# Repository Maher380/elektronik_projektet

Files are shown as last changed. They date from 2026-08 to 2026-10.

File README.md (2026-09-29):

# 🔥 CnB - Crash and Burn

Autonomous car school project built with C++ and ESP-IDF for the ESP32-S3.

This repository is used by team **CnB (Crash and Burn)** to develop the
software for an autonomous competition car.

The project starts from an ESP32-S3 driver library and includes:

- hardware abstraction through driver interfaces
- ESP32-S3 implementations for hardware-level code
- stubs for testing without hardware
- factory-based driver creation
- ESP-IDF CMake project structure

## Project Layout

```text
.
+-- 📁 firmware/                  ESP-IDF firmware project for the ESP32-S3
|   +-- CMakeLists.txt             Firmware project entry point
|   +-- 📁 main/                   Main ESP-IDF component
|       +-- CMakeLists.txt         Component source list and dependencies
|       +-- Kconfig.projbuild      Project configuration used by menuconfig
|       +-- 📁 include/            Public C++ headers
|       |   +-- 📁 driver/         Hardware driver interfaces and implementations
|       |   +-- 📁 system/         System-level interfaces and logic headers
|       +-- 📁 source/             C++ source files
|           +-- 📁 driver/         ADC, GPIO, timer, WiFi and serial drivers
|           +-- 📁 system/         Application logic and pin manager
|           +-- main.cpp           ESP-IDF application entry point
+-- 📁 hardware/                  Hardware design files
|   +-- 📁 kicad/                  KiCad schematics, PCB layout and exports
|   +-- 📁 ltspice/                LTspice simulations and component models
+-- README.md                      Project overview and workflow rules
+-- THIRD_PARTY_NOTICES.md         Attribution for imported starter code
```

The repository is split into two main areas:

- 📁 `firmware/` contains all software and embedded code.
- 📁 `hardware/` contains electronics design files, simulations and exports.

## Build

Use the ESP-IDF shell to build and flash:

```bash
cd firmware
idf.py set-target esp32s3
idf.py build
idf.py -p <PORT> flash monitor
```

Serial output is enabled over USB for later sensor testing. The application
prints `CnB serial ready` after the serial driver starts.

WiFi settings are configured with:

```bash
idf.py menuconfig
```

Open `Autonomous car network configuration` and set SSID and password. Do not
commit generated `sdkconfig` files with private credentials.

## Hardware

Hardware files are stored in `hardware/`.

- 📁 `hardware/kicad/` - KiCad project files for schematics, PCB layout, symbols, footprints and generated exports.
- 📁 `hardware/ltspice/` - LTspice simulation files, component models and circuit experiments.

## Branch Naming

Do not work directly on `main`. Create a branch for every task.

Branch names must use this format:

```text
<type>/<short-english-title>
```

Use a short English title. Prefer lowercase words separated with hyphens.

Allowed branch types:

- `feature/` - new functionality
- `fix/` - fixes for broken behavior
- `docs/` - documentation-only work
- `experiment/` - exploratory work not meant to be permanent
- `refactor/` - internal code cleanup without changing behavior
- `test/` - test-only changes
- `chore/` - maintenance, tooling or dependency updates
- `release/` - preparing a release
- `ci/` - pipeline or automation changes

Examples:

```bash
git switch -c docs/create-diary-structure
git switch -c feature/support-ir-sensor
```

If a branch belongs to a Jira task, include the Jira key in commits and pull
request titles:

```bash
git commit -m "CAR-12 support IR sensor"
```

## Pull Requests

Push your branch and open a pull request into `main`.

Each pull request should include:

- what was changed
- how it was tested
- the related Jira task, if one exists

## Vagrant system logic

The Vagrant logic runs the integrated IR/motor/servo loop. `main.cpp` starts
the target logic selected under Target car in `idf.py menuconfig`. Ford and the
third car are placeholders that leave the motor disabled until implemented.
See [system test setup and MQTT extensions](documentation/guides/main_system_test.md)
for wiring, behavior, configuration and host tests.

## Attribution

This project includes code derived from
`OliverEdman/cpp-driver-library-p02`, licensed under MIT. See
`THIRD_PARTY_NOTICES.md`.

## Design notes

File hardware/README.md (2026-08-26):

# Hardware

Hardware design files for the CnB autonomous car.

- `kicad/` contains KiCad project files for schematics and PCB layout.
- `ltspice/` contains LTspice simulations and component models.

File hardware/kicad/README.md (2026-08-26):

# KiCad

Place KiCad files here.

Typical files:

- `*.kicad_pro` - KiCad project
- `*.kicad_sch` - schematic
- `*.kicad_pcb` - PCB layout
- `symbols/` - project symbols
- `footprints/` - project footprints
- `exports/` - generated PDFs, Gerbers and BOM files

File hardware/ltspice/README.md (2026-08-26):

# LTspice

Place LTspice files here.

Typical files:

- `*.asc` - schematic simulation
- `*.asy` - custom symbols
- `*.lib` - component models
- `models/` - external models
- `simulations/` - simulation circuits

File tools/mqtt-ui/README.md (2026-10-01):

# MQTT-webbpanelen

Webbpanelen visar tio sekunders historik för tre IR-sensorer, begärd styrvinkel och motorpådrag. Här kan du starta/stoppa bilen och ändra körläge, duty, stoppavstånd och telemetriintervall.

**Ford:** kör `.\tools\mqtt-ui\start-ui.ps1 -Car ford`, se [Ford-guiden](../../documentation/guides/ford_manual_by_remote.md).

**Första gången:** följ [guiden från installation till körning](../../documentation/guides/mqtt_steg_for_steg.md).
För den integrerade körloopen, se även [systemtest och provade inställningar](../../documentation/guides/main_system_test.md).

**Redan konfigurerat:** starta brokern och bilen enligt steg 5 i guiden. Kör sedan från projektroten:

```powershell
cd 'C:\projekt\elektronik_projektet'
.\tools\mqtt-ui\start-ui.ps1
```

Byt sökvägen mot din egen projektrot. Öppna **http://127.0.0.1:8765** och kontrollera **LIVE MQTT**, **BROKER CONNECTED** och **CAR RECEIVING**.

**Andra enheter (t.ex. en telefon på cnb-net):** klicka på **LAN OFF** överst på sidan
på http://127.0.0.1:8765. Den visar då adressen att öppna på telefonen. Knappen syns och
fungerar bara på 127.0.0.1, och LAN-åtkomsten är alltid avstängd när servern startar.
Tillåt Node.js i Windows-brandväggen första gången. Alla på nätet kan då styra bilen.

Ändra inställningar med **Apply settings** och invänta kvittens. **Start car** aktiverar körning; **Stop car** avarmerar. Kör inte `run-car.ps1` samtidigt som panelen styr bilen.

Med systemtest-firmware visas även **Reaction distance**, **Loop interval** och
**Stop motor & test servo**. Servotestet stoppar motorn och ställer önskad vinkel;
ett nytt Start återgår till navigationen. Sensorernas beslutsavstånd visas separat
från mätvärdena. Systemtestet använder endast körläget `decide_action`.

För att prova panelen utan bil eller broker:

```powershell
.\tools\mqtt-ui\start-ui.ps1 -Demo
```

Demo använder simulerade värden och en förenklad körmodell, inte bilens exakta
väggkorrigering. Avsluta servern med **Ctrl+C** innan du byter läge.

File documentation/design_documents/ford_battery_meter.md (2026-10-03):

# Ford: Battery Meter

The Ford measures its drive battery (2S LiPo, 6.0–8.4 V) through a resistor
divider on `A3` (GPIO4). The firmware sends the voltage as `battery_v` in
`cnb/ford/telemetry`, and the Ford web page shows it on the BATTERY tile.

## Circuit

| Part | Nominal | Measured | From | To |
| --- | --- | --- | --- | --- |
| R1 | 100 kΩ | 101.24 kΩ | Battery + (after the switch) | `A3` |
| R2 | 33 kΩ | 32.99 kΩ | `A3` | `GND` |
| C1 | 150 nF (marked `154`) | 154 nF | `A3` | `GND` |

Battery voltage = pin voltage × (R1 + R2) / R2 ≈ pin voltage × 4.069, using
the measured values. C1 does not change the conversion; it gives the ADC a
steady charge to sample from. It is not a parameter in the code.

The meter averages its last 16 reads, one every 100 ms, so `battery_v` is
the average over about 1.6 s.

## Calibration points

Each row compares a multimeter on the battery terminals with `battery_v` at
the same moment. Add a row whenever you have a multimeter at hand,
preferably at other voltages, so the points spread over 6.0–8.4 V.

| Date | Multimeter (V) | `battery_v` (V) | Error (V) | Conditions |
| --- | --- | --- | --- | --- |
| 2026-10-03 | 7.38 | 7.34 | −0.04 (−0.5 %) | Not recorded. Firmware without correction. |

Write down the conditions (car standing still or driving, motors on or off),
because the voltage sags under load and the 1.6 s average lags behind it.

## Using the points

No correction is applied yet: −0.5 % is about 10 mV at the pin, which is
within the ESP32-S3 ADC's accuracy after its own calibration.

- **One point:** a gain factor, multimeter / `battery_v` (now 7.38 / 7.34 ≈ 1.005).
- **Two or more points, spread over the range:** a straight-line fit,
  multimeter = a × `battery_v` + b, which corrects both gain and offset.

The correction belongs where the battery is read in `fordLogic.cpp`, not in
`voltage_meter::Divider`, which stays a plain divider for any circuit.

A battery level (percent or time left) needs more than this: the LiPo's
discharge curve from voltage to charge. Calibrated voltages are the first
step towards it.

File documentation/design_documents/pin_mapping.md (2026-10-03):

# Arduino Nano ESP32: Code-To-Pin Reference

The driver factory uses the **ESP32-S3 GPIO number**, not the Arduino pin
number printed on the board.

> `factory.gpioOutput(2)` selects **GPIO2 = A1**, not Arduino pin D2.
> To select the board pin **D2**, use `factory.gpioOutput(5)` or
> `factory.pwm(5)`.

The `~` symbol marks a PWM-capable Arduino pin. The symbol is only a visual
label; it is not written in the C++ call.

## Pins Used By CnB - Vagrant

These are the calls and physical pins used by the current three-sensor code on
`SCRUM-56-fix-adc-support-for-multiple-ir-sensors`.

| Driver call | Pin on Arduino | Driver function | Connected hardware | Status |
| --- | --- | --- | --- | --- |
| `factory.adc(1)` | `A0 / ~D17` | 📈 ADC1_CH0 | Left IR sensor output | 🔵 Used |
| `factory.adc(2)` | `A1 / ~D18` | 📈 ADC1_CH1 | Center IR sensor output | 🔵 Used |
| `factory.adc(4)` | `A3 / ~D20` | 📈 ADC1_CH3 | Right IR sensor output | 🔵 Used |
| `factory.pwm(5)` | `~D2` | 〰️ PWM output | MP6550 IN1, forward | 🔵 Used |
| `factory.pwm(6)` | `~D3` | 〰️ PWM output | MP6550 IN2, reverse | 🔵 Used |
| `factory.gpioOutput(7)` | `~D4` | 🔌 Digital output | MP6550 nSLEEP | 🔵 Used |
| `factory.pwm(9)` | `~D6` | 〰️ PWM output | steering servo | 🔵 Used |
| `factory.odometer(18)` | `~D9` | 🔌 Digital input (interrupt) | A3144 Hall-effect odometer sensor | 🔵 Used |
| `factory.gpioInput(10)` | `~D7` | 🔌 Digital input (interrupt) | SRF05 Echo, via 5 V → 3.3 V divider | 🔵 Used |
| `factory.gpioOutput(17)` | `~D8` | 🔌 Digital output | SRF05 Trigger | 🔵 Used |

Power connections do not use driver factory calls:

| Pin on Arduino | Connection |
| --- | --- |
| `VIN` | Approximately 7.2 V battery supply after the power switch |
| `GND` | Common ground for Arduino, MP6550, regulator, and sensors |
| External regulated 5 V rail | IR sensor and/or SRF05 power; the demo used an L7805CV |

## Pins Used By CnB - Ford

| Driver call | Pin on Arduino | Driver function | Connected hardware | Status |
| --- | --- | --- | --- | --- |
| `factory.gpioOutput(5)` | `~D2` | ⚡ Digital output | A89301 BRAKE (high = brake) | 🔵 Used |
| `factory.gpioOutput(7)` | `~D4` | ⚡ Digital output | A89301 DIR | 🔵 Used |
| `factory.pwm(8)` | `~D5` | 〰️ PWM output, 20 kHz | A89301 SPD/SCL (speed) | 🔵 Used |
| `factory.pwm(9)` | `~D6` | 〰️ PWM output | steering servo (pulse width) | 🔵 Used |
| `factory.adc(4)` | `A3 / ~D20` | 📈 ADC1_CH3 | Drive battery voltage divider: R1 101.24 kΩ from battery + (after the switch), R2 32.99 kΩ and 154 nF to `GND` | 🔵 Used |

## Code Value To Board Pin

Use the first column when passing a pin to `gpioInput()`, `gpioOutput()`,
`pwm()`, or `adc()`.

### Legend

| Symbol | Meaning |
| --- | --- |
| 🔵 | Used by the current CnB firmware |
| 🟢 | Available for a future connection |
| 🟡 | Available, but shared with a standard peripheral or onboard function |
| 🔴 | Avoid; blocked by the current pin manager |
| ✅ | Supported by the current driver |
| ⚠️ | Supported by the chip, but not by the current ADC1-only driver |
| `~` | PWM-capable Arduino pin |

| GPIO in code | Pin on Arduino | ADC status | PWM status | Common function | Availability |
| ---: | --- | --- | --- | --- | --- |
| `0` | `B1 / ~D15` | - | 🔴 Blocked | RGB LED green / strapping | 🔴 Avoid |
| `1` | `A0 / ~D17` | ✅ ADC1_CH0 | ✅ | Analog / digital | 🔵 Left IR sensor |
| `2` | `A1 / ~D18` | ✅ ADC1_CH1 | ✅ | Analog / digital | 🔵 Center IR sensor |
| `3` | `A2 / ~D19` | 🔴 ADC1_CH2 blocked | 🔴 Blocked | Strapping | 🔴 Avoid |
| `4` | `A3 / ~D20` | ✅ ADC1_CH3 | ✅ | Analog / digital | 🔵 Right IR sensor |
| `5` | `~D2` | ✅ ADC1_CH4 | ✅ | Digital / PWM | 🔵 MP6550 IN1 |
| `6` | `~D3` | ✅ ADC1_CH5 | ✅ | Digital / PWM | 🔵 MP6550 IN2 |
| `7` | `~D4` | ✅ ADC1_CH6 | ✅ | Digital / PWM | 🔵 MP6550 nSLEEP |
| `8` | `~D5` | ✅ ADC1_CH7 | ✅ | Digital / PWM | 🟢 Available |
| `9` | `~D6` | ✅ ADC1_CH8 | ✅ | Digital / PWM | 🔵 Steering servo |
| `10` | `~D7` | ✅ ADC1_CH9 | ✅ | Digital / PWM | 🔵 SRF05 Echo |
| `11` | `A4 / ~D21` | ⚠️ ADC2_CH0 | ✅ | I2C SDA | 🟡 Shared function |
| `12` | `A5 / ~D22` | ⚠️ ADC2_CH1 | ✅ | I2C SCL | 🟡 Shared function |
| `13` | `A6 / ~D23` | ⚠️ ADC2_CH2 | ✅ | Analog / digital | 🟢 Available |
| `14` | `A7 / ~D24` | ⚠️ ADC2_CH3 | ✅ | Analog / digital | 🟢 Available |
| `17` | `~D8` | ⚠️ ADC2_CH6 | ✅ | Digital / PWM | 🔵 SRF05 Trigger |
| `18` | `~D9` | ⚠️ ADC2_CH7 | ✅ | Digital / PWM | 🔵 Odometer (A3144 Hall sensor) |
| `21` | `~D10` | - | ✅ | Digital / PWM | 🟢 Available |
| `38` | `~D11` | - | ✅ | SPI COPI | 🟡 Shared function |
| `43` | `~D1 / TX0` | - | ✅ | UART transmit | 🟡 Shared function |
| `44` | `~D0 / RX0` | - | ✅ | UART receive | 🟡 Shared function |
| `45` | `~D16` | - | 🔴 Blocked | RGB LED blue / strapping | 🔴 Avoid |
| `46` | `B0 / ~D14` | - | 🔴 Blocked | RGB LED red / strapping | 🔴 Avoid |
| `47` | `~D12` | - | ✅ | SPI CIPO | 🟡 Shared function |
| `48` | `~D13` | - | ✅ | SPI SCK / built-in LED | 🟡 Shared function |

GPIO values not listed above are not exposed as normal Arduino Nano ESP32
header pins. Do not use them only because `PinManager::isPinValid()` returns
true; the current pin manager does not verify that a GPIO is physically exposed
on this board.

## How The Factory Interprets A Number

| Code | Meaning |
| --- | --- |
| `factory.gpioInput(n)` | Configure GPIO `n` as a digital input |
| `factory.gpioOutput(n)` | Configure GPIO `n` as a digital output |
| `factory.pwm(n)` | Route a PWM output to GPIO `n` |
| `factory.adc(n)` | Use GPIO `n` as an ADC1 input if it maps to ADC1 |

For example:

```cpp
auto leftSensor = factory.adc(1);        // GPIO1 -> A0 -> ADC1_CH0
auto motorIn1 = factory.pwm(5);          // GPIO5 -> ~D2
auto motorSleep = factory.gpioOutput(7); // GPIO7 -> ~D4
```

The three IR sensors share one `ADC_UNIT_1` handle and use channels 0, 1, and
3. The ADC2-capable pins shown in the table cannot be initialized by the
current ADC driver because it deliberately accepts ADC1 only.

## Power And Control Pins

| Pin on Arduino | Type | Meaning |
| --- | --- | --- |
| `VIN` | Power input | External supply input for the Nano ESP32 |
| `3V3` | Power output | Regulated 3.3 V output; GPIO is not 5 V tolerant |
| `VUSB` | Power output | USB-derived supply; do not assume it is active from VIN |
| `GND` | Ground | Common electrical reference |
| `RESET` | Control input | Reset when pulled low |

## Sources

- [Arduino Nano ESP32 full pinout](https://docs.arduino.cc/resources/pinouts/ABX00083-full-pinout.pdf)
- [Arduino Nano ESP32 datasheet](https://docs.arduino.cc/resources/datasheets/ABX00083-datasheet.pdf)
- [Espressif ESP32-S3 GPIO reference](https://docs.espressif.com/projects/esp-idf/en/stable/esp32s3/api-reference/peripherals/gpio.html)

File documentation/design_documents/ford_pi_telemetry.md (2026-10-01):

# Ford: Raspberry Pi telemetry over MQTT

The contract between the Ford's Raspberry Pi (code in the `slam_test` repo) and the
web page in this repo (`tools/mqtt-ui`). The Pi reports what it **measures** with the
camera through SLAM, so the operator can compare it with what the car was **asked**
to do. Terms are defined in [CONTEXT.md](../../CONTEXT.md): *measured speed*,
*wheel angle*, *steering command*, *speed command*.

## Topics

| Topic | Retained | QoS | Sent |
| --- | --- | --- | --- |
| `cnb/ford/pi/telemetry` | no | 0 | every 200 ms |
| `cnb/ford/pi/status` | yes | 1 | on connect, and as the MQTT last will |

The Pi is part of the Ford, so its topics sit under `cnb/ford`. It has its own
status, so the page can tell "Pi offline" from "ESP offline".

## Broker login

- Username and password: the same as the Ford's ESP, `cnb-ford`.
- **Client ID: `cnb-ford-pi`.** It must differ from the ESP's (`cnb-ford`); two
  clients with the same ID keep disconnecting each other.
- The ACL ([mosquitto-acl.example](../../tools/mqtt/mosquitto-acl.example)) lets
  `cnb-ford` write both Pi topics and `cnb-dashboard` read them.
- The broker is on the car network, `mqtt://192.168.137.1:1883`.

## `cnb/ford/pi/status`

Exactly like the ESP's status:

```json
{ "schema_version": 1, "online": true }
```

Publish it retained when connected, and register
`{ "schema_version": 1, "online": false }` (retained) as the last will so the broker
reports the Pi offline if it drops off.

## `cnb/ford/pi/telemetry`

```json
{
  "schema_version": 1,
  "measured_speed_mps": { "slam": 0.42 },
  "wheel_angle_deg": { "slam": -12.3 },
  "slam_state": "tracking",
  "cpu_temp_c": 61.2
}
```

| Field | Unit | Meaning |
| --- | --- | --- |
| `schema_version` | — | Always `1`. Other versions are ignored. |
| `measured_speed_mps` | m/s | Measured speed, one entry per source. Positive is forward. |
| `wheel_angle_deg` | degrees | Wheel angle, one entry per source. Negative is left, 0 straight ahead, positive right. |
| `slam_state` | — | `"tracking"`, `"lost"` or `"starting"`. Anything else makes the page ignore the message. |
| `cpu_temp_c` | °C | The Pi's CPU temperature. |

### Sources

A real-world value is always reported with its source. The key names the source,
the value is a number or `null`:

- `slam`: worked out by SLAM from the camera. The only source so far.
- Later sources get their own key, for example
  `"measured_speed_mps": { "slam": 0.42, "odometer_left_rear": 0.45 }`.
  Keys use `a-z`, `0-9` and `_`, at most 32 characters.

### When a value is `null`

- `slam_state` is not `"tracking"`: both SLAM values are `null`.
- The car moves slower than **0.2 m/s**: the SLAM wheel angle is `null`. It is worked
  out from turn rate and speed, so it is unknown when the car stands still or creeps.
  Tune the threshold in `slam_test`.
- Any value the Pi cannot work out: `null`, never a made-up 0.

## What the page does with it

- **Status strip, PI · SLAM:** SLAM state, or STALE/OFFLINE; CPU temperature amber
  from 70 °C, red from 80 °C ("throttling, SLAM may lag"; the Pi 5 slows itself down
  at about 80–85 °C).
- **Steering card:** the SLAM wheel angle beside the steering command converted to
  degrees with the Ford's full-lock angle (`FULL_LOCK_DEG` in `public/ford.mjs`,
  a placeholder of 25° until measured). A difference above 5° is flagged.
- **Speed card:** the SLAM measured speed beside the speed command, not converted:
  without a speed loop a speed command has no fixed m/s.
- **Charts:** the last 30 seconds of command and measured, for steering and speed.
- **Freshness:** the page assumes the fixed 200 ms rate and treats Pi data older than
  500 ms as stale. If the Pi's rate changes, change `PI_INTERVAL_MS` in `core.mjs`
  and `public/ford.mjs` too.
- **Demo:** `start-ui.ps1 -Car ford -Demo` simulates the Pi with this payload.

## Checking from the laptop

```powershell
& 'C:\Program Files\mosquitto\mosquitto_sub.exe' -h 127.0.0.1 -u cnb-dashboard -P <password> -t 'cnb/ford/pi/#' -v
```

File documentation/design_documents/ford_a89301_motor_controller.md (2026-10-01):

# Ford: A89301 BLDC Motor Controller

## Human introduction
Initially the A89301 had bad settings for the ford Engine. In order to fix this a configuration application which communicated with the A89301 from the esp32s3 through I2C was developed. This tool can also be used to tune the A89301 later on.

## AI text

Bench bring-up and tuning of the drive motor for **ford**, done on branch
`feature/add_A89301_motor_driver` (September 2026). The car was on a stand,
wheels in the air, powered from a lab supply at 7.4 V. All numbers below are
**without load** unless stated otherwise.

## Hardware

| Part | Details |
| --- | --- |
| Motor controller | Pololu A89301-based sensorless brushless motor controller, 50 V, 11 A (Pololu 5357, board `md47a`) |
| Motor | Sensorless brushless, 8000 KV, 3 wires, about 0.5 Ω phase to phase (measured) |
| Pole pairs | 1 (derived: 12 Hz electrical per wheel rev/s matches 8000 KV at 1 pole pair and a gear ratio of about 12) |
| Wheel | 34 mm diameter, 0.107 m circumference |
| Controller MCU | Arduino Nano ESP32 (ESP32-S3) |

The A89301 is a field-oriented (FOC) sensorless controller. It estimates the
rotor position from the motor model (resistance, inductance) and an observer
with gains `PID_P` and `PID_I`. These parameters must fit the motor.

## Wiring

### Configuration wiring (I2C), used by `A89301_CONFIG_MODE`

| A89301 board | ESP32-S3 (Nano pin / GPIO) | Notes |
| --- | --- | --- |
| VIN, GND (screw terminal) | – | 7.4 V supply (2S LiPo range 6.4–8.4 V) |
| SA, SB, SC | – | Motor phases |
| GND (header) | GND | Common ground is required |
| IOREF | 3V3 | Logic level 3.3 V. Also powers the FAULT LED |
| SPD/SCL | A5 / GPIO12 | I2C SCL. **Add 4.7 kΩ pull-up to 3.3 V** (the board has none on SCL) |
| FG/SDA | A4 / GPIO11 | I2C SDA. The board has a pull-up to IOREF |
| DIR | D4 / GPIO7 | High = forward in the test apps |
| BRAKE | D2 / GPIO5 | High = brake. **Fit a 10–12 kΩ pull-up to 2V8**, see Safety |
| FLT | not connected | Open drain, pulled up to IOREF |
| – | D9 / GPIO18 | A3144 wheel odometer, 1 magnet per revolution |
| – | A0 / GPIO1 | TMP36 on the motor can (ADC1) |

### PWM wiring, used by `MOTOR_TEST_MODE`

Same as above, but SPD is driven with 20 kHz PWM from **D5 / GPIO8** instead of
the I2C bus: **move the SPD/SCL wire from A5 to D5**. The A89301 EEPROM is
configured for PWM speed input (`SPD_MODE` 0, `CLOCK_PWM` 0, `PWMIN_RANGE` 0 =
PWM above 2.8 kHz).

The motor test app does not use FG/SDA (A4), FLT, the odometer (D9) or the
TMP36 (A0). They may stay connected.

Speed is set as a PWM duty 0.0–1.0 over the serial monitor. Start with at least
0.08, lower to 0.065 for the slowest steady speed and stay at or below 0.7 (see
Measured performance).

> **The motor test app has no motor temperature, stall or speed limit
> protection.** Keep runs short and watch the motor. Use the configuration app
> for longer tests.

## Saved A89301 configuration

Only three EEPROM words were changed from the configuration we received. All
Allegro-only bits are at their default values (checked by the programmer before
writing).

| EEPROM address | Original | Saved | Changed fields |
| --- | --- | --- | --- |
| 12 | `0x0028` | `0x01FF` | `PID_P` 40 → **255**, `MOTOR_INDUCTANCE` 0 → **1** |
| 13 | `0x011E` | `0x0114` | `PID_I` 30 → **20** |
| 21 | `0xC020` | `0xC120` | `SPEED_INPUT_OFF_THRESHOLD` 10 % → **6 %** |

To restore the original configuration, write the original values back to
addresses 12, 13 and 21.

Full EEPROM contents after saving (addresses 8–22):

```
 8 0x275E    12 0x01FF    16 0x0A6C    20 0x0B25
 9 0x7120    13 0x0114    17 0x2000    21 0xC120
10 0x00DC    14 0x0E15    18 0x8E0D    22 0x925E
11 0xD880    15 0x39B1    19 0x5500
```

Other relevant settings (unchanged): open loop speed control
(`SPEED_CLOSE_LOOP` 0), `RATED_SPEED` 1886 (1000 Hz), `RATED_VOLTAGE` 7.4 V,
`RATED_CURRENT` 2.5 A (current limit about 3.25 A), `MOTOR_RESISTANCE` 113
(about 0.24 Ω phase to centre, matches the measurement), `FG_PIN_DIS` 1 (FG
always high, I2C friendly), `RESTART_ATTEMPT` 3 times, standby disabled.

## Tuning conclusions

**Symptom:** the motor accelerated for about 2 s and then stopped without a
fault. The chip stayed in state "spinning" and reported speeds up to its
limit (about 1080 Hz) while the wheel stood still.

**Cause:** the observer gains and the inductance did not fit this small
high-KV motor. The position estimate ran ahead of the rotor and the chip lost
the motor, without detecting it.

How it was found (logs with I2C readback and a wheel odometer):

1. Resistance, acceleration and rated speed had no or negative effect.
2. Allegro's diagnostic "open drive" (stepper mode, PID 0) ran steadily, which
   points to the observer (application note UM-A89301, step 16D).
3. PID sweeps: high `PID_P` and `PID_I` ran steadily with inductance 0, but at
   high motor current (about 4.5 A peak for 10 rev/s) and warm motor.
4. Inductance 1 was more efficient but needed a new PID: with inductance 1 the
   best combination is high `PID_P`, low `PID_I`. `PID_I` ≥ 80 stalled,
   `PID_I` 20 was the most stable.
5. Inductance 2 and higher failed at low speed.

**Result with inductance 1, PID 255/20:** steady from 0.5 to 6 m/s, in both
directions, with about half the motor current of the first stable setting.

## Measured performance (no load, 7.2 V at the board)

Speed is the chip estimate divided by 12, times the wheel circumference. It
matched the odometer where the odometer was reliable.

| Demand | Speed | Supply current | Power | Notes |
| --- | --- | --- | --- | --- |
| 0.06 | 0.5 m/s | 190 mA | 1.4 W | Only reachable after starting higher (see below). Close to the stop threshold |
| 0.065 | 0.57 m/s | 195 mA | 1.4 W | Recommended lowest speed |
| 0.08 | 0.77 m/s | 215 mA | 1.5 W | Lowest demand that starts from standstill |
| 0.12 | 1.26 m/s | 290 mA | 2.1 W | |
| 0.20 | 2.32 m/s | 430 mA | 3.1 W | |
| 0.30 | 3.61 m/s | 660 mA | 4.7 W | |
| 0.40 | 5.02 m/s | 890 mA | 6.3 W | |
| 0.70 | 6.03 m/s | 1150 mA | 8.1 W | Speed flattens above 0.40 in step tests |

- **Starting:** 12 of 12 starts from standstill were steady at 0.12–0.25.
  Startup (position detection) takes about 1.1 s at about 1.35 A.
- **Low speed:** the chip starts above 7.8 % demand and stops below 5.9 %.
  Start at 0.08, then lower the demand to 0.065 for about 0.57 m/s.
- **Energy:** about 0.33–0.46 Wh/km without load. The Raspberry Pi 5 will
  likely use more power than the drive motor.
- **Chip limit:** keep the electrical speed below about 1000 Hz (A89301 limit
  about 1085 Hz). The test apps stop at 1000 Hz.

## Safety

- **Pull resistors for driving (PWM wiring):** fit these before the car drives.

  ```text
                                   2V8 (A89301 board) ─┐
                                                      [R1] 10–12 kΩ
                                                       │
     D2 / GPIO5  ──────────────────────────────────────┴── BRAKE   (high = brake)
     D4 / GPIO7  ───────────────────────────────────────── DIR
     D5 / GPIO8  ──────────────────────────────────────┬── SPD/SCL (20 kHz PWM)
                                                       │   (no pull-up to 3V3 here)
                                                      [R2] 10–12 kΩ
                                                       │
                                   GND ────────────────┴── GND (header)
     D6 / GPIO9  ──────────────────────────────────────┬── steering servo signal
                                                      [R3] 10–12 kΩ (optional)
                                   GND ────────────────┘
  ```

  - **R1** keeps the brake on whenever the motor board has battery power and the
    ESP32 does not drive BRAKE (reset, flashing, crash, Nano unpowered). 2V8 is
    the A89301's own 2.8 V output, made for pull-ups (max 10 mA).
  - **R2** makes a floating SPD read as 0 % speed.
  - **Remove the 4.7 kΩ SCL pull-up** from the I2C wiring when SPD moves to D5:
    it turns a floating SPD into full speed.
  - **R3** only stops the servo twitching during flashing.
  - Do not connect 2V8 or VM (battery voltage) to the Nano.
  - **Check** with the Nano unplugged and the battery on: BRAKE ≈ 2.8 V,
    SPD ≈ 0 V. Then flash once on the stand; the wheels must not move.
- **BRAKE pull-up:** the board pulls BRAKE low (brake off) by default. While
  the ESP32 is reset or flashed its pins float, and in the I2C wiring SPD/SCL
  is pulled high, which the chip reads as a large speed demand. **The wheels
  spin during flashing.** A 10 kΩ pull-up from BRAKE to 3.3 V keeps the brake
  on whenever the ESP32 is not driving the pin. Recommended for ford.
- **Motor temperature:** the config app stops above 45 °C and waits for
  32 °C between runs. These limits are temporarily low because the TMP36 is
  taped over two layers of electrical tape and reads low and late. Raise them
  to 60 / 40 °C when the sensor has direct contact with the motor can.
- **Stall protection:** the config app brakes if the chip reports spinning
  above 50 Hz but the wheel gives no odometer pulse for 1 s.

## Known issues and open items

- **Load test:** not done yet. Low speed torque (demand 0.06–0.08) and the
  current limit may need changes with the car on the ground.
- **Odometer:** misses pulses above about 2.5 m/s with the current mounting.
- **Speed plateau** above demand 0.40 in step tests is not explained. It does
  not matter at SLAM speeds.
- **Slower than 0.5 m/s** needs closed loop speed control or other gearing.
- **Speed control in the final car:** PWM on SPD (D5) for now (ManualByRemote
  uses it). I2C readback of speed, current and state is a later step.

## Tools

The A89301 configuration app (`A89301_CONFIG_MODE` in `firmware/main/source/main.cpp`,
code in `firmware/main/source/test_app/a89301_config_test.cpp`) reads, changes
and saves the settings over I2C. Type `h` for all commands. The most useful:

| Command | Purpose |
| --- | --- |
| `d` | Dump EEPROM and working registers with decoded fields |
| `m` | Live monitor: speed, wheel, currents, VBB, demand, state, temperature |
| `set <FIELD> <value>` | Change a field in the working register (lost at power cycle) |
| `run <L> <P> <I> [speed] [s]` | One test run with given inductance and PID |
| `profile up` / `profile start` | Speed steps / repeated starts, with power table |
| `save`, `save yes` | Show / program the working register changes into EEPROM |

Enable the ESP-IDF monitor log with Ctrl+T, Ctrl+L to keep a log file.

## References

- [Pololu A89301 motor controller](https://www.pololu.com/product/5357)
- [A89301 datasheet](https://www.pololu.com/file/0J2192/A89301-Datasheet.pdf)
- [A89301 application note UM-A89301](https://cdck-file-uploads-global.s3.dualstack.us-west-2.amazonaws.com/digikey/original/2X/e/e846acadea51a0fbdfe7fda1454ab9dd98a9ff01.pdf)
  (tuning procedure, state codes, Allegro-only bits)

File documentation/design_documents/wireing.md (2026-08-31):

# Wiring Diagram

## Vagrant
### ESP32

| Pin | Connection | Color |
|-----|---|---|
| GND | Common GND | Black |
| D2 | MC6550 IN1 | Orange |
| D3 | MC6550 IN2 | Brown |
| D4 | MC6550 !SLP | Gray |
| VIN | Common battery | Red |
| A0 | IR Sensor | Yellow |

### MC6550

| Pin | Connection | Color |
|-----|---|---|
| GND | Common GND | Black |
| VIN | Common battery | Red |
| OUT1 | Forward Engine | Green |
| OUT2 | Backward Engine | Blue |
| IN1 | D2 (ESP32) | Orange |
| IN2 | D3 (ESP32) | Brown |
| !SLP | D4 (ESP32) | Gray |

### IR Sensor

| Wire | Connection | Color |
|-----|---|---|
| Black wire | Common GND | Black |
| Red wire | Common battery | Red |
| Yellow wire | A0 (ESP32) | Yellow |

### Power Switch

| Connection | Link | Color |
|---|---|---|
| Red wire 1 | Common battery | Red |
| Red wire 2 | Battery voltage | Orange |

### Battery

| Terminal | Connection | Color |
|---|---|---|
| Black | Common ground | Black |
| Red | Power switch | Red |

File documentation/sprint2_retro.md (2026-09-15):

# Sprint 2 retro
- Fortsätt sitta tillsammans, men jobba också  tillsammans.
- Flera testmiljöer.
- Dokumentera testresultat på ett mer effektivt sätt (Digital i Git).
- Skapa ett flödesdiagram för att underlätta förståelse av kod och flöde.
- Skapa en mer meningsfull stand-up genom att:
    - Börja med vi där vi alla jobbar mot ett gemensamt mål som ar prio 1 för dagen. 
    - Ta sedan sekundära "Jag" uppgifter.
- Var tydlig med att be om hjälp, säkerställ bekräftelse av hjälp behovet (Ack).
- Fortsätt med låg fokus på Jira.
- Diskutera PR efter stand-up.
# Brainstorm/planering
- Bli färdig med Vagranten innan vi börjar med nästa. `DoD` = Vagranten kör ett varv helt automont.
- Dela upp funktioner i olika testmiljöer.
- Testerna omfattar både `hårdvara` & `mjukvara`.
- Börja med att testa på en `Arduino Uno` och `Arduino IDE`.
    - DOKUMENTERA RESULTAT EFTER VARJE TEST!!.
    - Enhetstester
        - Motorkontroller.
        - IR-Sensor right.
        - IR-Sensor left.
        - IR-Sensor center.
        - Servo.
    - Intergrationstester (exempel).
        - IR-sensor R+C+L
        - Motorkontroller + IR-Sensor.
        - Servo + IR-Sensor
    - System/logik- tester
        - Koppla ihop alla funktioner.
- Flera drive modes.
- Batteristatus.
- Löda på stiftlistor på utvecklingsPCB:t i syfte att få en mer modulär design.
- Implementera MPU inklusive enhetstestmiljö.
- Implementera magnetsensorer inklusive enhetstestmiljö.
- Implementera SLAM.
- Ekonomi/BOM dokumentation i Git.
- Skapa AGENTS.md i GitHub.
- Skapa inköpslista och uppdatera ekonomi/BOM i Git.
    - IR-Sensorer/avståndsmätare. 
    - Kablar till IR-Sensorer.
    - Kablar till batteri.
    - Bättre strömbrytare.

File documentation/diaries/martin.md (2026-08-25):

# Dagbok

## 2026-08-18

- Gruppen startades upp.
- Daniel riggade Jira på en grundläggande nivå.
- Martin hade skapat en Discord-server sedan tidigare.
- Maher hade skapat ett Git-repo.
- Martin skapade en principskiss för mjukvarans samverkan.

_Cirka 3 timmar arbete._
## 2026-08-19

- Daniel demonterade bilarna och kom fram till att:
	- Vagranten behöver cirka 1 A. Hastigheten varierar beroende på spänningen från 0 till 7,2 V, vilket är vad batteriet kan ge. Omvänd polaritet ger omvänd färdriktning.
	- Masseratin drar också cirka 1 A. Batteriet (3 × 1,5 V AA) är den nuvarande spänningsbegränsningen.
- Maher jobbade med IR-sensorn och skapade ett enkelt program som läser av spänningen som genereras av IR-sensorn.
- Martin hejade mest på.

_Cirka 3 timmar arbete._

## 2026-08-20

- Stångade mig blodig i Jira och kom fram till att jag föredrar GitHub Projects.

**TODO:** Stämma av skiftet med Henrik.

_Cirka 3 timmar arbete._

## 2026-08-21 - 25
- Inledande granskning av PR chore: import ESP-IDF driver library startpoint enhancement
- Jobbat med DoD
- skissat på enklaste lösningen på köra fram och stoppa vid hinder, med hjälp av IR-sensorer och en enkel pwm-reglering.
- skapade struktur för dagbok.

_Cirka 6 timmar arbete._

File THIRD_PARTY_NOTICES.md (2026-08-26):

Third Party Notices
===================

This repository includes code derived from:

- Repository: https://github.com/OliverEdman/cpp-driver-library-p02
- Upstream commit used as starter: 4aa1553964dc9f0e07de63856d025199d88307a2
- License: MIT

MIT License

Copyright (c) 2026 Oliver Edman Chrantz

Permission is hereby granted, free of charge, to any person obtaining a copy
of this software and associated documentation files (the "Software"), to deal
in the Software without restriction, including without limitation the rights
to use, copy, modify, merge, publish, distribute, sublicense, and/or sell
copies of the Software, and to permit persons to whom the Software is
furnished to do so, subject to the following conditions:

The above copyright notice and this permission notice shall be included in all
copies or substantial portions of the Software.

THE SOFTWARE IS PROVIDED "AS IS", WITHOUT WARRANTY OF ANY KIND, EXPRESS OR
IMPLIED, INCLUDING BUT NOT LIMITED TO THE WARRANTIES OF MERCHANTABILITY,
FITNESS FOR A PARTICULAR PURPOSE AND NONINFRINGEMENT. IN NO EVENT SHALL THE
AUTHORS OR COPYRIGHT HOLDERS BE LIABLE FOR ANY CLAIM, DAMAGES OR OTHER
LIABILITY, WHETHER IN AN ACTION OF CONTRACT, TORT OR OTHERWISE, ARISING FROM,
OUT OF OR IN CONNECTION WITH THE SOFTWARE OR THE USE OR OTHER DEALINGS IN THE
SOFTWARE.

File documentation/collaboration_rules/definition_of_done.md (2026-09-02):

# Definition of Done

Det här dokumentet beskriver när en task eller user story räknas som färdig.

## Statusmarkeringar

- `[ ]` Kravet ingår i Definition of Done.
- `[x]` Kravet är identifierat, men ingår inte i Definition of Done ännu.

## Task-nivå: kod

Gäller kodtasks, till exempel features, buggar och refaktoreringar.

- [ ] Koden är implementerad och uppfyller taskens beskrivning.
- [ ] Koden kompilerar och kör utan fel.
- [x] Enhetstester finns och passerar för tasken.
- [ ] Det finns rimlig felhantering för uppenbara fel och specialfall.
- [ ] Koden är kommenterad där logiken inte är självförklarande.
- [x] Koden följer gruppens namn- och formateringsstandard.
- [ ] Ändringen är pushad via en pull request med ett begripligt commit-meddelande.
- [ ] Koden är granskad av minst en annan gruppmedlem.
- [ ] Pull requesten är godkänd och mergad till `main` av ticketansvarig.
- [ ] Tasken är markerad som klar på boarden.

## Task-nivå: hårdvarudesign

- [ ] Designen är dokumenterad i Git-repot.
- [x] Dokumentationen följer gruppens dokumentationsstruktur.
- [ ] Ändringen är pushad via en pull request med ett begripligt commit-meddelande.
- [ ] Designen är granskad och förstådd av minst en annan gruppmedlem.
- [ ] Pull requesten är godkänd och mergad till `main` av ticketansvarig.
- [ ] Tasken är markerad som klar på boarden.

## User story-nivå

- [ ] Alla tasks kopplade till storyn är klara, granskade, testade och mergade.
- [x] Funktionen uppfyller storyns acceptanskriterier.
- [ ] Alla enhetstester passerar tillsammans efter integrering.
- [ ] Hela programmet bygger och kör med all storyfunktionalitet på plats.
- [ ] Funktionen är testad som helhet, inklusive integration och användarflöde.
- [ ] Nödvändig dokumentation är uppdaterad, till exempel README och användarinstruktioner.
- [ ] Inga kända allvarliga buggar kvarstår.
- [ ] Gruppen är överens om att storyn är färdig.

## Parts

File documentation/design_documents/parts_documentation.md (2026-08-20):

 #initial setup
## Vagrant
 - Battery: 7.2 V, 350 mAh
 - Rear-Wheel Drive
 - HJ-244016RX - car controller (will not be used)
 - Engine 050 Carbon brush motor set
 - Servo based Steering system - pwm signal -> steering direction

 ## Maserati MC20
 - Battery:  3 AA batteries
 - Rear-Wheel Drive
 - [not checked] - car controller (will not be used) 
 - engine some kind of motor set 
 - Steering system - not checked - likely not servo based.

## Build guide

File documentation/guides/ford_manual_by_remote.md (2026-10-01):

# Ford: drive from the web page (ManualByRemote)

The Ford has one drive style, **ManualByRemote**: you set the steering command
(−90 left … +90 right) and the speed command (−100 reverse … +100 forward) with
two sliders in the web page, and the car follows them over MQTT.

Broker, `.env` and Wi-Fi are set up as in the [MQTT guide](mqtt_steg_for_steg.md).
This guide only lists what is different for the Ford.

## 1. Before the first drive

- Wire the A89301 for **PWM speed** and fit the pull resistors, see
  [the motor controller doc](../design_documents/ford_a89301_motor_controller.md#safety).
- Broker: copy the updated `tools/mqtt/mosquitto-acl.example` to
  `%USERPROFILE%\cnb-mqtt\acl` and add the car's account, then restart Mosquitto:

  ```powershell
  & 'C:\Program Files\mosquitto\mosquitto_passwd.exe' "$env:USERPROFILE\cnb-mqtt\passwords" cnb-ford
  ```

## 2. Build and flash

In `idf.py menuconfig`, choose **Target car → Ford**. The MQTT client ID and
username become `cnb-ford`; a Ford build with another client ID does not compile.
Set Wi-Fi, broker URI and the `cnb-ford` password as for Vagrant, then build and
flash.

## 3. Start the page

```powershell
.\tools\mqtt-ui\start-ui.ps1 -Car ford
```

Open **http://127.0.0.1:8765**. Without a car: add `-Demo`.

### Drive from a phone on cnb-net

The page is only reachable from the laptop until you turn on LAN access:

1. On the laptop, open **http://127.0.0.1:8765** and click the **LAN OFF** chip
   at the top. It turns into **LAN ON · 192.168.137.1:8765** (your address may differ).
   The chip is only shown, and only works, on 127.0.0.1.
2. The first time, Windows asks whether Node.js may accept connections. Allow it
   for the network type cnb-net uses (the hotspot is often *Public*).
3. On the phone (connected to cnb-net), open the address the chip shows.

Anyone on the network can then open the page and drive the car. Click the chip
again to turn LAN access off; phones lose the page at once. LAN access is always
off when the console starts.

## Drive with the arrow keys

Instead of dragging the sliders you can use the **arrow keys** or the
▲ ◀ ▼ ▶ pad on the page (works on a touch screen too):

| Press | Does |
| --- | --- |
| ↑ / ↓ | Speed +1 / −1 |
| ← / → | Steering −10° (left) / +10° (right) |
| 0 | Speed 0 (steering stays) |

Holding a key repeats at the keyboard's repeat rate. The value stays where it is
when you let go; press the **0** key, the 0 button, double-click the slider or
panic stop to stop.

## What the Raspberry Pi measures

When the Pi publishes (see [the Pi telemetry contract](../design_documents/ford_pi_telemetry.md)),
the page shows what the camera measured beside what the car was asked to do:

| Where | Shows |
| --- | --- |
| Status strip, **PI · SLAM** | TRACKING / TRACKING LOST / STARTING, or STALE / OFFLINE; CPU temperature (amber ≥ 70 °C, red ≥ 80 °C) |
| Steering card, **WHEEL · SLAM** | Wheel angle in degrees; orange when more than 5° from the command. "—" below 0.2 m/s |
| Speed card, **MEASURED · SLAM** | Measured speed in m/s |
| Charts | Last 30 s of command and measured, for steering and speed |

The command in degrees uses the Ford's full-lock angle, a placeholder of 25° until
it has been measured (`FULL_LOCK_DEG` in `tools/mqtt-ui/public/ford.mjs`).

## How the car behaves

| Situation | Car |
| --- | --- |
| Boot, disarmed, panic stop, heartbeat lost (3 s), MQTT lost | Brakes and centres the steering |
| Speed command 0 | No drive: motor coasts, still armed |
| Speed command changes direction | Brakes 300 ms, then drives the other way |
| No drive command for 500 ms | No drive, still armed; drives on when commands return |
| Start | Speed stays 0 until you move the speed slider |

Speed command ±1 … ±100 maps to duty 0.08 … 0.15 (about 0.8 … 1.5 m/s
unloaded). These values are compiled into `fordLogic.cpp` until they move to NVS.

## Bench checklist

Run it with the car on the stand, wheels in the air, before driving on the floor.

- [ ] Flash: the wheels do not move while flashing or booting.
- [ ] Page shows BROKER CONNECTED, CAR RECEIVING and drive style ManualByRemote.
- [ ] Start: motor state goes from BRAKED to NO DRIVE; moving the speed slider is
      needed before the wheels turn.
- [ ] Speed +20 / +100: wheels turn forward; the CAR value matches the slider.
- [ ] Speed −40 from forward: motor state shows BRAKING briefly, then DRIVING REV.
- [ ] Steering −90 / 0 / +90: wheels follow; the CAR value matches the slider.
- [ ] Press ↑ / ↓: the speed slider and its CAR value change by 1 per press.
- [ ] Press ← / →: the steering slider and its CAR value change by 10 per press.
- [ ] Drive at speed +20 and press the 0 key: speed slider and CAR value go to 0.
- [ ] Pull the laptop's Wi-Fi: DRIVE TIMEOUT (wheels coast) within about 0.5 s,
      then disarmed (brake) within about 3 s.
- [ ] Switch to another tab while driving: the car brakes and disarms.
- [ ] Panic stop from a second tab: the car brakes and disarms.

> @todo No automated tests yet for the ManualByRemote rules (firmware) or the
> drive stream (console). Add them before relying on this beyond bench tests.

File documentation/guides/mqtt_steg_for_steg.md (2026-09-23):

# MQTT och webbpanelen – från installation till körning

**Första gången:** följ steg 1–5.
**När allt är konfigurerat:** gå direkt till steg 5.

Byt exempelvägen `C:\projekt\elektronik_projektet` mot din projektrot, där `firmware` och `tools` finns.

Guiden gäller MQTT-firmwaren och webbpanelen tillsammans. Merga MQTT-PR:n först och webbpanelens PR därefter. Innan webbpanelen finns kan du använda terminalskripten längre ned.

## 1. Installera verktygen

Installera på Windows:

- **ESP-IDF 6.0** – för att bygga och flasha ESP32.
- **Mosquitto** – MQTT-broker och klientverktyg. Exemplen använder `C:\Program Files\mosquitto`.
- **Node.js 20 eller senare** – för webbpanelen.

Anslut datorn och bilen till samma WiFi, exempelvis din mobilhotspot.

Öppna PowerShell och gå till projektroten:

```powershell
cd 'C:\projekt\elektronik_projektet'
```

**Alla `tools`-kommandon i guiden körs från denna mapp.**

## 2. Konfigurera MQTT-brokern – en gång

Brokern körs på datorn och förmedlar meddelanden mellan bilen och webbpanelen.

Skapa mappar och kopiera behörighetsfilen:

```powershell
New-Item -ItemType Directory -Force "$env:USERPROFILE\cnb-mqtt\data"
Copy-Item .\tools\mqtt\mosquitto-acl.example "$env:USERPROFILE\cnb-mqtt\acl"
```

Skapa två konton. Kommandona frågar efter lösenord:

```powershell
& 'C:\Program Files\mosquitto\mosquitto_passwd.exe' -c "$env:USERPROFILE\cnb-mqtt\passwords" cnb-vagrant
& 'C:\Program Files\mosquitto\mosquitto_passwd.exe' "$env:USERPROFILE\cnb-mqtt\passwords" cnb-dashboard
```

- `cnb-vagrant` används av bilen.
- `cnb-dashboard` används av webbpanelen och terminalskripten.

**Använd `-c` bara när lösenordsfilen skapas första gången. Det skriver över en befintlig fil.**

Skapa brokerkonfigurationen:

```powershell
$brokerPath = "$env:USERPROFILE/cnb-mqtt".Replace('\', '/')
@"
listener 1883
allow_anonymous false
password_file $brokerPath/passwords
acl_file $brokerPath/acl
persistence true
persistence_location $brokerPath/data/
log_type error
log_type warning
log_type notice
"@ | Set-Content "$env:USERPROFILE\cnb-mqtt\mosquitto.conf" -Encoding ascii
```

Tillåt inkommande **TCP-port 1883** i Windows-brandväggen för det lokala nätverket där bilen ansluter.

## 3. Konfigurera webbpanelen – en gång

Öppna konfigurationsfilen:

```powershell
notepad .\tools\mqtt\.env
```

Skapa filen om den saknas. Skriv följande och ersätt lösenordet med det du valde för `cnb-dashboard`:

```dotenv
CNB_MQTT_HOST=127.0.0.1
CNB_MQTT_PORT=1883
CNB_MQTT_USERNAME=cnb-dashboard
CNB_MQTT_PASSWORD=DITT_DASHBOARD_LÖSENORD
```

Spara filen. `127.0.0.1` fungerar eftersom webbpanelen och brokern körs på samma dator.

## 4. Konfigurera bilen – en gång

Kör i PowerShell:

```powershell
ipconfig
```

Notera **IPv4-adressen för datorns WiFi-adapter**. Bilen behöver denna adress för att nå brokern.

Öppna sedan **ESP-IDF-terminalen**:

```powershell
cd 'C:\projekt\elektronik_projektet\firmware'
idf.py menuconfig
```

Under **Autonomous car network configuration**, fyll i:

| Inställning | Värde |
|---|---|
| Enable WiFi | Aktiverat |
| WiFi SSID / password | WiFi-namn och WiFi-lösenord |
| Enable MQTT telemetry and runtime control | Aktiverat |
| MQTT broker URI | `mqtt://DATORNS_IPV4:1883` |
| MQTT client ID | `cnb-vagrant` |
| MQTT username | `cnb-vagrant` |
| MQTT password | Lösenordet du skapade för bilen |

Använd **datorns WiFi-adress**, inte `127.0.0.1`, i bilen.

Kontrollera också:
**Component config → ESP System Settings → Main task stack size = 8192**.

Spara och avsluta. Inställningarna sparas i `firmware/sdkconfig` och behålls vid vanlig byggning och flashning.

## 5. Starta systemet – varje gång

Använd tre terminaler och låt dem vara öppna.

### Terminal 1: broker – PowerShell

```powershell
& 'C:\Program Files\mosquitto\mosquitto.exe' -c "$env:USERPROFILE\cnb-mqtt\mosquitto.conf" -v
```

Hoppa över detta om rätt broker redan körs.

### Terminal 2: bilen – ESP-IDF-terminal

Anslut ESP32 med USB:

```powershell
cd 'C:\projekt\elektronik_projektet\firmware'
idf.py build flash monitor
```

Om rätt firmware redan är flashad räcker `idf.py monitor`.

### Terminal 3: webbpanelen – PowerShell

```powershell
cd 'C:\projekt\elektronik_projektet'
.\tools\mqtt-ui\start-ui.ps1
```

Öppna **http://127.0.0.1:8765**.

När panelen visar **LIVE MQTT**, **BROKER CONNECTED** och **CAR RECEIVING** är systemet anslutet.

## Använd webbpanelen

| Du vill… | Gör så här |
|---|---|
| Välja körläge | Stoppa bilen, välj **Driver style**, tryck **Apply settings** |
| Ändra motorpådrag | Ändra **Drive duty**, 0–1 |
| Ändra stoppgräns | Ändra **Stop distance**, 30–70 cm |
| Ändra hur ofta telemetri skickas | Ändra **Telemetry**, i ms |
| Skicka inställningarna till bilen | Tryck **Apply settings** och invänta kvittens |
| Köra automatiskt | Tryck **Start car** |
| Stoppa bilen | Tryck **Stop car** |

Körläget väljer en av körfunktionerna i `logic.cpp`. Duty 0 är inte samma sak som stopp: bilen kan fortfarande vara armerad och styra. Använd **Stop car** för att avarmera. Manuellt servotest, reaktionsavstånd och justerbart loopintervall ingår inte i denna version.

Kör inte `run-car.ps1` samtidigt som webbpanelen styr bilen.

## Köra utan webbpanel – valfritt

Från projektroten kan du använda terminalskripten i stället:

```powershell
.\tools\mqtt\run-car.ps1
```

Låt terminalen vara öppen för heartbeat. Stoppa från en annan terminal i projektroten:

```powershell
.\tools\mqtt\stop-car.ps1
```

## Spara sensordata – valfritt

Öppna ytterligare en PowerShell i projektroten:

```powershell
.\tools\mqtt\log-telemetry.ps1 -OutputPath .\tools\mqtt\logs\mitt-test.ndjson
```

För att bara visa telemetri i terminalen:

```powershell
.\tools\mqtt\watch-telemetry.ps1
```

Avsluta med **Ctrl+C**.

## Avsluta eller felsök

Tryck först **Stop car**. Avsluta webbservern, loggningen och brokern med **Ctrl+C**.
Avsluta ESP-IDF-monitorn med **Ctrl+]**.

| Problem | Kontrollera |
|---|---|
| Connection refused | Brokern måste köra på rätt adress och port. |
| Not authorized | Kontrollera kontots lösenord och brokerfilens ACL. |
| Panelen ansluter men bilen saknas | Kontrollera WiFi, datorns IPv4, bilens brokeradress och brandväggen. |
| Skriptet hittas inte | Kör från projektroten, inte `firmware`. |
| Nytt WiFi eller hotspot | Kontrollera datorns IPv4. Uppdatera bilens `menuconfig` och flasha om vid ändring. |
| Bilen står still | Kontrollera Start, duty och stopporsaken i panelen. |

Lösenord finns lokalt i `sdkconfig` och `tools/mqtt/.env`. Lägg inte dessa filer i Git.

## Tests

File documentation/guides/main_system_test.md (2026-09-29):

# Vagrants systemlogik

Den lokalt provade loopen ligger i `firmware/main/source/system/logic/vagrantLogic.cpp`.
`firmware/main/source/main.cpp` startar den billogik som valts i menuconfig.
Drivrutiner hämtas via factory. `Control::authorizeAction()` kontrollerar MQTT-start,
anslutning och heartbeat; vägval och motor-/servokommandon bestäms i Vagrants logik.

Bygg, flasha och starta MQTT enligt [MQTT-guiden](mqtt_steg_for_steg.md).
Checka ut hela grenen: testet kräver även runtime- och kommunikationsfilerna.

## Koppling och beteende

| Funktion | Anslutning |
| --- | --- |
| IR vänster / fram / höger | A0 / A1 / A3 (GPIO 1 / 2 / 4) |
| MP6550 IN1 / IN2 / nSLEEP | D2 / D3 / D4 (GPIO 5 / 6 / 7) |
| Servo | D6 (GPIO 9), center 330 Hz |

- Standardvärden: stopp 30 cm, reaktion 40 cm, duty 0,5, sensorloop 20 ms,
  telemetri 1000 ms. Sparad MQTT-konfiguration kan ersätta dessa efter anslutning.
- Avstånd över reaktionsgränsen samt NaN/inf behandlas som reaktionsgränsen.
  Negativa avstånd begränsas till noll. Ursprungliga mätvärden och ADC loggas separat.
- Om alla tre beslutsavstånd är högst stoppgränsen bromsar bilen.
- När framåt når reaktionsgränsen korrigerar bilen mjukt bort från en närliggande
  sidovägg. Sidornas närhet innanför stoppavståndet jämförs med 3 cm dödzon,
  2°/cm och högst ±30°. Exempel med standardgränser: 70/60/15 cm ger −24°.
- Annars ger en ensam längsta vänstersida −90° och en ensam längsta högersida +90°.
  Framåt som längst eller delad förstaplats ger rakt fram. NaN räknas som fri
  väg enligt den testade regeln; det är inte en bekräftelse från sensorn.
- Start krävs efter uppstart. Stopp, förlorad MQTT och utebliven heartbeat stoppar
  motorn. Ett hinder som försvinner tillåter fortsatt körning medan bilen är armed.
- Manuellt servotest stoppar motorn. Ett nytt Start återgår till automatisk körning.

## Extra MQTT-inställningar

Publicera följande JSON till `cnb/vagrant/config/set` (QoS 1, retained).
Använd en högre `revision` för varje ändring under samma uppstart:

```json
{"schema_version":1,"revision":1,"stop_distance_cm":30,"reaction_distance_cm":40,"loop_interval_ms":20,"drive_duty":0.5,"telemetry_interval_ms":1000,"driver_style":"decide_action"}
```

Stoppavstånd: 1–100 cm. Reaktionsavstånd: 1–200 cm och större än stoppavståndet.
Loopintervall: 20–1000 ms. Duty: 0–1. Telemetri: 200–5000 ms.
Utelämnade `reaction_distance_cm` och `loop_interval_ms` behåller aktuella värden.
Testloopen stöder endast `decide_action`; andra körlägen avvisas.

Servotest via `cnb/vagrant/command` (QoS 1, **inte retained**):

```json
{"schema_version":1,"request_id":1,"session_id":"manual-test","command":"servo","angle_deg":-30}
```

Vinkeln får vara −90 till +90°. `request_id` måste vara högre än tidigare start-
och servokommandon under samma uppstart. Ett vanligt stoppkommando avslutar testet.

Webbpanelen visar både uppmätta avstånd och beslutsavstånd. Reaktionsavstånd,
loopintervall och manuellt servotest kan styras där. Start/stopp och heartbeat
fungerar som tidigare. Kör endast en operatör åt gången.

## Provade värden på bilen

Dessa värden fungerade bäst vid den senaste körningen, men är **inte standardvärden**:
duty **0,44**, stopp **45 cm**, reaktion **52 cm**, loop **20 ms**, telemetri **200 ms**.
De finns också som kommentar överst i `vagrantLogic.cpp`.

Från projektroten, med broker och bil anslutna:

```powershell
.\tools\mqtt\set-config.ps1 -StopDistanceCm 45 -ReactionDistanceCm 52 -LoopIntervalMs 20 -DriveDuty 0.44 -TelemetryIntervalMs 200 -DriverStyle DecideAction
.\tools\mqtt\test-servo.ps1 -Angle -30
```

Det andra kommandot är ett separat servotest som stoppar motorn. Kontrollera alltid
kvittensen i `command/state`. Det första kommandot sparar inställningarna retained
hos brokern; firmwarestandarderna ändras inte.

Odometerdrivrutinerna från senaste `main` finns kvar. Vagrant kör systemloopen
i `VagrantLogic::run()` i stället för den äldre `Logic::run()` och odometerns separata testläge.

## Automatiskt test på datorn

Med Python, Zig och en lokal kopia av cJSON:s `cJSON.c` och `cJSON.h`, kör från
projektroten (ersätt sökvägarna):

```text
python tests/run_system_test.py --zig <sökväg-till-zig> --cjson-dir <cJSON-mapp>
```

Testet kör den riktiga Vagrant-loopen med simulerade sensorer, MQTT och PWM.
Det kontrollerar 24 vägvalsfall, väggkorrigering, broms/återstart, servotest, inställningar, telemetri och
heartbeat-timeout. Det ersätter inte provning på bilen.

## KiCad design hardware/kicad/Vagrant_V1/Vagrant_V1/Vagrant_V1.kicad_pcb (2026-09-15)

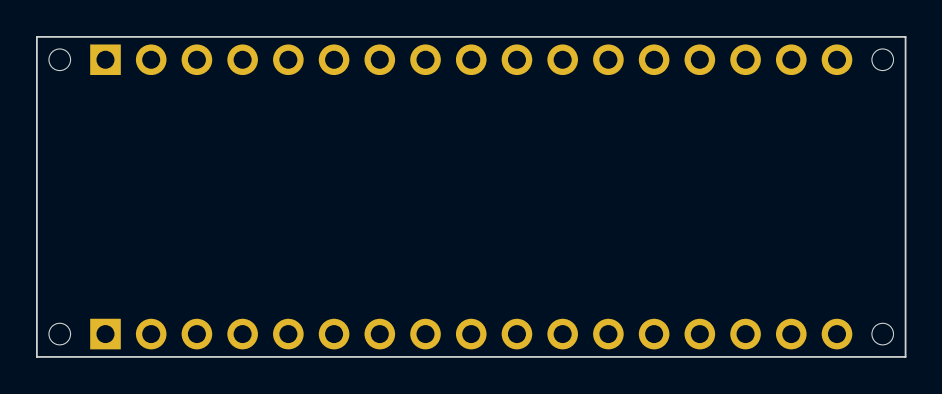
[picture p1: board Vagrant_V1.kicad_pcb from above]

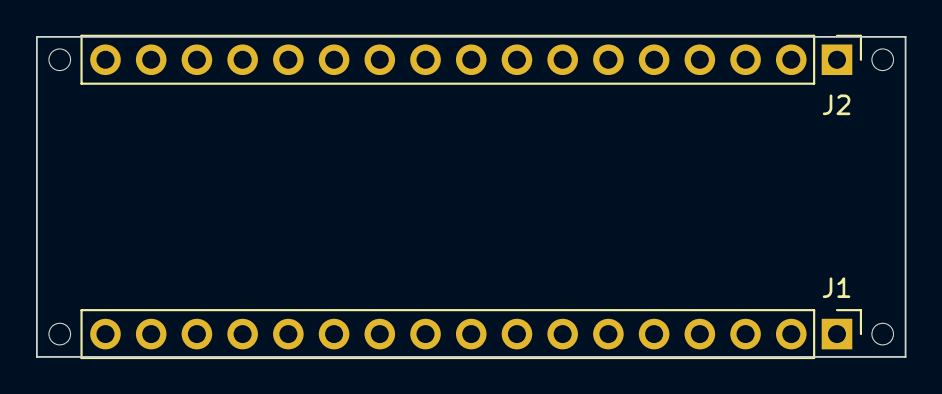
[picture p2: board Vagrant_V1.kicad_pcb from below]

Board: 2 copper layers, 48.3 x 17.8 mm, 6 parts (2 on the bottom side), 2 nets, no tracks yet.

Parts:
J1: Analog; PinHeader_1x17_P2.54mm_Vertical
J2: Digital; PinHeader_1x17_P2.54mm_Vertical
MH1, MH2, MH3, MH4: MountingHole_1.2mm

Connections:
/~RESET: J1.13, J2.13
GND: J1.14, J2.12

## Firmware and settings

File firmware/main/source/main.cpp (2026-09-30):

/** @file main.cpp @brief Start the selected car logic. */

/** @attention Uncomment DRIVER_TEST_MODE to run the local driver test code. */
// #define DRIVER_TEST_MODE

/** @attention Uncomment ODOMETER_TEST_MODE to run a minimal odometer-only test app. */
// #define ODOMETER_TEST_MODE

/** @attention Uncomment MOTOR_TEST_MODE to run a minimal A89301 BLDC motor test app. */
// #define MOTOR_TEST_MODE

/** @attention Uncomment A89301_CONFIG_MODE to read, change and save the A89301 settings over I2C. */
// #define A89301_CONFIG_MODE

// if compiling a test purpose variant
#if defined(DRIVER_TEST_MODE) || defined(ODOMETER_TEST_MODE) || defined(MOTOR_TEST_MODE) || defined(A89301_CONFIG_MODE)

#include "test_app/test_app.h"

#else

#include <atomic>
#include "driver/factory/esp32s3.h"
#include "sdkconfig.h"
#include "system/logic/target.h"

#endif // if compiling a test purpose variant

#if CONFIG_CNB_ENABLE_MQTT
static_assert(CONFIG_ESP_MAIN_TASK_STACK_SIZE >= 8192,
              "MQTT requires Main task stack size >= 8192 in menuconfig.");
#endif

extern "C" void app_main(void)
{
    #if defined(DRIVER_TEST_MODE)
    app::test_app::runDriverTest();
    #elif defined(ODOMETER_TEST_MODE)
    app::test_app::runOdometerTest();
    #elif defined(MOTOR_TEST_MODE)
    app::test_app::runMotorTest();
    #elif defined(A89301_CONFIG_MODE)
    app::test_app::runA89301ConfigTest();
    #else
    std::atomic<bool> stop{false};
    driver::factory::Esp32s3 factory;
    app::logic::TargetLogic logic{factory};
    logic.run(stop);
    #endif
}

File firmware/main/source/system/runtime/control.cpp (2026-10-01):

#include "system/runtime/control.h"

#include <algorithm>
#include <cmath>

namespace app::runtime
{
namespace
{
bool isFiniteInRange(float value, float minimum, float maximum) noexcept
{
    return std::isfinite(value) && (value >= minimum) && (value <= maximum);
}
} // namespace

Control::Control(bool systemTest, bool manualByRemote) noexcept
    : mySystemTest{systemTest}, myManualByRemote{manualByRemote}
{
    if (myManualByRemote)
    {
        // The operator watches the echoed commands, so telemetry must feel live.
        myConfiguration.driverStyle = navigation::DriverStyle::ManualByRemote;
        myConfiguration.telemetryIntervalMs = 200U;
    }
}

bool Control::supportsDriverStyle(navigation::DriverStyle style) const noexcept
{
    // ManualByRemote cars have no obstacle distances for the autonomous styles.
    if (myManualByRemote) { return style == navigation::DriverStyle::ManualByRemote; }
    switch (style)
    {
        case navigation::DriverStyle::DecideAction: return true;
        case navigation::DriverStyle::SlowLeft:
        case navigation::DriverStyle::SlowRight:
        case navigation::DriverStyle::GradualSweep: return !mySystemTest;
        case navigation::DriverStyle::ManualByRemote: return false;
    }
    return false;
}

ConfigurationResult Control::applyConfiguration(
    const ConfigurationRequest& request) noexcept
{
    if (request.revision == 0U)
    {
        return ConfigurationResult::InvalidRevision;
    }
    if (!isFiniteInRange(request.values.stopDistanceCm, mySystemTest ? 1.0F : 30.0F, mySystemTest ? 100.0F : 70.0F))
    {
        return ConfigurationResult::StopDistanceOutOfRange;
    }
    if (!isFiniteInRange(request.values.driveDuty, 0.0F, 1.0F))
    {
        return ConfigurationResult::DriveDutyOutOfRange;
    }
    if ((request.values.telemetryIntervalMs < 200U)
        || (request.values.telemetryIntervalMs > 5000U))
    {
        return ConfigurationResult::TelemetryIntervalOutOfRange;
    }

    Configuration candidate = request.values;
    if (!request.hasReactionDistance) { candidate.reactionDistanceCm = myConfiguration.reactionDistanceCm; }
    if (!request.hasLoopInterval) { candidate.loopIntervalMs = myConfiguration.loopIntervalMs; }
    if (!isFiniteInRange(candidate.reactionDistanceCm, 1.0F, 200.0F)
        || (mySystemTest && candidate.reactionDistanceCm <= candidate.stopDistanceCm))
    {
        return ConfigurationResult::ReactionDistanceOutOfRange;
    }
    if (candidate.loopIntervalMs < 20U || candidate.loopIntervalMs > 1000U)
    {
        return ConfigurationResult::LoopIntervalOutOfRange;
    }
    if (!request.hasDriverStyle) { candidate.driverStyle = myConfiguration.driverStyle; }
    if (!supportsDriverStyle(candidate.driverStyle)) { return ConfigurationResult::InvalidDriverStyle; }
    // Reject the entire update: neither values nor revision may advance.
    if (candidate.driverStyle != myConfiguration.driverStyle && myControlState != ControlState::Disarmed)
    {
        return ConfigurationResult::DriverStyleRequiresDisarmed;
    }

    if (myHasConfigurationRevision)
    {
        if ((request.revision == myConfigurationRevision)
            && sameConfiguration(candidate, myConfiguration))
        {
            return ConfigurationResult::Duplicate;
        }
        if (request.revision <= myConfigurationRevision)
        {
            return ConfigurationResult::StaleRevision;
        }
    }

    myConfiguration = candidate;
    myConfigurationRevision = request.revision;
    myHasConfigurationRevision = true;
    return ConfigurationResult::Applied;
}

bool Control::setDriverStyle(navigation::DriverStyle style) noexcept
{
    if (!supportsDriverStyle(style)) { return false; }
    if (style != myConfiguration.driverStyle && myControlState != ControlState::Disarmed) { return false; }
    myConfiguration.driverStyle = style;
    return true;
}

void Control::setMqttConnected(bool connected) noexcept
{
    if (myMqttConnected && !connected && (myControlState == ControlState::Armed))
    {
        disarm(StateReason::MqttDisconnected);
    }
    myMqttConnected = connected;
}

CommandResult Control::handleCommand(const Command& command,
                                     std::uint32_t nowMs) noexcept
{
    if (command.sessionId[0] == '\0')
    {
        return {false, CommandError::InvalidSession};
    }

    switch (command.type)
    {
        case CommandType::Start:
            if (myActuatorFault) { return {false, CommandError::NotArmed}; }
            if (!command.hasRequestId || command.requestId == 0U)
            {
                return {false, CommandError::InvalidRequest};
            }
            if (!myMqttConnected)
            {
                return {false, CommandError::MqttDisconnected};
            }

            if (command.requestId <= myLastControlRequestId)
            {
                // A QoS-1 retransmission may be acknowledged, but never renews
                // a lease or re-arms a stopped session.
                if (command.requestId == myLastStartRequestId
                    && myControlState == ControlState::Armed
                    && isActiveSession(command.sessionId)
                    && (nowMs - myLastHeartbeatMs) < HeartbeatTimeoutMs)
                {
                    return {true, CommandError::None};
                }
                return {false, CommandError::StaleRequest};
            }
            myLastControlRequestId = command.requestId;
            myLastStartRequestId = command.requestId;
            myServoTest = false;
            // A new session never inherits the previous session's drive commands.
            myDrive = {};
            myHasDrive = false;
            myActiveSession = command.sessionId;
            myLastHeartbeatMs = nowMs;
            myControlState = ControlState::Armed;
            myMotionState = MotionState::Stopped;
            myStateReason = StateReason::None;
            return {true, CommandError::None};

        case CommandType::Stop:
            myLastControlRequestId = std::max(myLastControlRequestId, command.requestId);
            disarm(StateReason::OperatorStop);
            return {true, CommandError::None};

        case CommandType::Servo:
            if (!mySystemTest || myActuatorFault || !command.hasRequestId
                || command.requestId == 0U
                || !isFiniteInRange(command.servoAngleDegrees, -90.0F, 90.0F))
            {
                return {false, CommandError::InvalidRequest};
            }
            if (!myMqttConnected) { return {false, CommandError::MqttDisconnected}; }
            if (command.requestId <= myLastControlRequestId) { return {false, CommandError::StaleRequest}; }
            myLastControlRequestId = command.requestId;
            disarm(StateReason::OperatorStop);
            myServoAngleDegrees = command.servoAngleDegrees;
            myServoTest = true;
            return {true, CommandError::None};
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

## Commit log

2026-08-20 chore: import ESP-IDF driver library startpoint
2026-08-25 Fixa GPIO-riktning och toggle
    [esp32s3.cpp]
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2026-08-26 Updated factory to support IR-sensor drivers
2026-08-26 Update logic to support IR-sensor drivers
2026-08-27 Add PWM and motor driver support
2026-08-27 fix: add motor sleep output to logic
2026-08-27 fix: yield main loop and initialize drivers
    [logic.cpp]
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2026-09-02 add interface for servo
2026-09-03 Share ADC1 across sensor channels
2026-09-03 Handle invalid IR sensor readings
2026-09-03 Correct ESP32-S3 pin validation
    [esp32s3.cpp]
2026-09-03 Align factory stub motor interface
2026-09-03 Support three IR sensors in logic
2026-09-03 Add multi-channel sensor tests
2026-09-03 feat(logic): add multi-sensor obstacle handling
    - Add forward, left, and right IR sensor drivers
    - Track and log distances for all sensors
    - Choose motor heading based on closest obstacle
    - Validate driver initialization before enabling the motor
2026-09-03 SCRUM-57 Clarify Arduino pin mapping
2026-09-03 add basic but non functional servo skeleton
2026-09-04 add esp32s3 to weights documentation
2026-09-04 feat(pwm): support changing PWM frequency
2026-09-04 feat(servo): add Vagrant frequency-based servo driver
2026-09-04 SCRUM-57 Move pin mapping documentation
2026-09-04 feat(servo): calibrate steering and transactional PWM updates
2026-09-04 feat(logic): add driving strategies and sensor fail-safe
    [logic.cpp]
2026-09-04 update pin usage documentation
2026-09-07 fix bad steering logic
    [logic.cpp]
2026-09-08 Kicad scematic for Version 1 of the Vagrant car
    [Vagrant_V1.kicad_pcb, Vagrant_V1.kicad_sch]
2026-09-16 fix: adjust servo center frequency to 330 Hz (was 300 Hz)
2026-09-16 feat: add manual drive style for serial-controlled motor testing
    Adds a DriverStyle::Manual mode driven by serial commands (SPEED,
    FORWARD/BACKWARD, BRAKE/COAST, STOP, DRIVESTYLE, PWMFREQFWD/PWMFREQBWD,
    HELP) so the MP6550 motor's speed, direction, brake mode, and PWM
    frequency can be exercised directly for bench testing without
    requiring the IR-avoidance logic to be active. Motor commands other
    than HELP/DRIVESTYLE are ignored unless already in Manual mode.
    [logic.cpp]
2026-09-16 fix: set PWM duty percentage instead of frequency for manual motor test commands
    Replaces PWMFREQFWD/PWMFREQBWD with PWMDUTYFWD/PWMDUTYBWD, which set
    the forward/backward PWM duty cycle (0-100%) directly, since that was
    the actually intended per-channel control for bench testing.
    [logic.cpp]
2026-09-18 Allow both upper and lower case in serial commands
2026-09-18 feat: compensate loop delay for a steady tick rate in Logic::run
    Measure elapsed time with esp_timer_get_time() at the start of each
    iteration and again just before the delay, then subtract the work
    time from tickPeriod_ms so the loop keeps a steady cadence instead of
    drifting by however long processing took.
    [logic.cpp]
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2026-09-23 fix bad merge conflict resolve in logic.run
    [logic.cpp]
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2026-09-23 Adapt and make use of GPIO for Hall sensor A3144
2026-09-23 fix GPIO initialized checks
    [esp32s3.cpp]
2026-09-24 fix: include runtime support for the tested main loop
    [control.cpp, main.cpp, manager.cpp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]
2026-09-24 feat: add proportional wall clearance correction at 20 ms
    [main.cpp]
2026-09-29 Add SRF05 ultrasonic distance sensor driver and test mode
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2026-09-29 Fix: correct bad include path
    [vagrantLogic.cpp]
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2026-09-30 fix gpio read of output pins
    Output pins are configured without input buffer, so gpio_get_level() always read 0. read() now returns the last written state for output pins.
    [esp32s3.cpp]
2026-09-30 fix serial write of long messages over usb
    The USB Serial/JTAG TX ring buffer (256 bytes) rejects larger writes, so long messages were silently dropped. Send them in 128 byte chunks.
    [esp32s3.cpp]
2026-09-30 add A89301 motor driver
    Driver for the Pololu A89301 sensorless BLDC controller: PWM on SPD for speed, GPIO for DIR and BRAKE, implements driver::motor::Interface. Includes host unit tests.
2026-09-30 add I2C master driver
    driver::i2c interface, ESP32-S3 implementation using the ESP-IDF i2c_master API with cached device handles, and a register device stub for host tests.
2026-09-30 add A89301 I2C register and EEPROM programmer
    Reads and writes A89301 registers over I2C, documented field table, I2C speed control and EEPROM programming with read-back. Allegro-only bits and factory words are protected. Includes host unit test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
2026-09-30 separate prototype applications from main
    Same pattern as e884009 on feature/add_ir_srf05 (without the SRF05 test app): test apps live in test_app/ and main.cpp only selects them. driver_test.cpp and odometer_test.cpp are identical to that c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
2026-09-30 add A89301 motor test app
    MOTOR_TEST_MODE: drives the A89301 with PWM on SPD, speed and direction set over the serial monitor.
2026-09-30 add A89301 configuration app
    A89301_CONFIG_MODE: read, change and save the A89301 settings over I2C, live monitor, PID sweeps, run and speed profile commands, with motor temperature (TMP36), stall and speed limit protection.
    [a89301_config_test.cpp, main.cpp]
2026-09-30 document ford A89301 motor controller
    Wiring, saved EEPROM configuration with the original values, tuning conclusions, measured speed and power, safety notes and open items.
2026-09-30 fix(logic): keep the tick delay correct when a loop pass overruns
    The remaining time was computed from an unsigned elapsed time, so a pass
    longer than the tick period wrapped to a huge delay. Use signed values so
    an overrun gives a negative remainder and no delay.
    [logic.cpp]
2026-09-30 feat(servo): add the Ford pulse-width servo driver
    Ford's steering is a standard hobby servo: the pulse width sets the angle
    and the pulse is sent at 50 Hz. The steering command is scaled on each side
    of center, so 0 always gives the center pulse, and commands past full lock
    are clamped instead of rejected.
    Calibration from the bench test on experiment/steering-test: left 1000 us,
    center 1500 us, right 2000 us, just inside the end stops (about 900-1000 us
    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
2026-09-30 feat(factory): add fordServo
    Creates the Ford servo driver on the ESP32-S3 and the servo stub in host
    tests.
2026-09-30 refactor(factory): rename servo to vagrantServo
    With fordServo beside it, a plain servo() read as the default servo. Neither
    car is the default, so name the Vagrant servo after its car.
2026-09-30 add simple usage of servo from empty FordLogic::run
2026-10-01 feat(factory): add fordMotor
    Create the A89301 BLDC motor driver (SPD PWM, DIR, BRAKE) through the
    driver factory. The stub factory returns a simulated motor.
2026-10-01 feat(ford): drive by remote (ManualByRemote)
    Add the ManualByRemote driver style: the Ford takes live steering and
    speed commands over MQTT and drives the A89301 motor by PWM on SPD.
    A missing drive command brakes the car (drive timeout) and a direction
    change brakes before reversing. The MQTT client ID and username follow
    the target car, and the example ACL gets the cnb-ford user.
    Document the BRAKE and SPD pull resistors and the PWM pins.
    [control.cpp, fordLogic.cpp, logic.cpp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]
2026-10-01 feat(mqtt-ui): add Ford ManualByRemote web page
    start-ui.ps1 -Car ford serves a drive page with steering and speed
    sliders, arrow keys and an on-screen pad. While the tab is in control it
    streams drive commands every 100 ms through a long-lived mosquitto_pub.
    After every start the car gets speed 0 until the operator moves the
    speed slider. -Demo simulates the Ford.
2026-10-01 feat(mqtt-ui): optional LAN access from 127.0.0.1
    A LAN chip on both pages lets devices on the local network (e.g. a phone
    on cnb-net) open the console. It is off at start and can only be toggled
    from a browser on 127.0.0.1; LAN hosts are accepted only on the server
    bound to that address. Session IDs now use crypto.getRandomValues, since
    crypto.randomUUID is missing over plain http on the LAN.
2026-10-01 feat(mqtt-ui): show Ford Pi SLAM telemetry
    The Ford's Raspberry Pi publishes what SLAM measures on cnb/ford/pi/telemetry
    and cnb/ford/pi/status. The Ford page shows it beside the commands:
    - status strip: SLAM state and CPU temperature (amber >= 70 C, red >= 80 C)
    - steering card: wheel angle vs command in degrees (full lock placeholder 25)
    - speed card: measured speed in m/s beside the speed command
    - 30 s charts of command vs measured for steering and speed
    The demo simulates the Pi. The ACL example grants the Pi topics, and the
    contract for slam_test is in documentation/design_documents/ford_pi_telemetry.md.
    Also fixes the readout "differs" highlight, which a more specific rule hid.
    Co-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
2026-10-03 feat(driver): add voltage meter for a resistor divider
    voltage_meter::Divider turns an ADC reading back into the voltage before
    the divider, (R1 + R2) / R2, and averages the last 16 reads. It works with
    any ADC driver, so it is named after the circuit, not the chip.
2026-10-03 feat(ford): report drive battery voltage in telemetry
    The Ford reads its battery divider on A3 every 100 ms and sends the
    average as battery_v. The field is left out when there is no reading,
    so Vagrant's telemetry does not change.
2026-10-03 feat(mqtt-ui): show Ford battery voltage
    A battery tile on a 5-9 V bar, with the low (6.8 V) and critical (6.4 V)
    limits marked and named in text. The demo drains a fake battery so every
    state can be seen.
2026-10-03 docs(ford): record battery meter circuit and first calibration point
    Multimeter 7.38 V, battery_v 7.34 V. More points will allow a gain and offset correction later.
2026-10-03 docs(driver): draw the voltage divider wiring
    A diagram replaces the one-line wiring description, kept generic: Vin rather than a battery, and no board pins.
